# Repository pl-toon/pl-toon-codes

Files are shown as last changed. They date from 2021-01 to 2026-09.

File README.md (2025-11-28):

# PL-TOON
Repository for a multi agent experimental platooning platform 

# Platform in action (Youtube Link)
PL-TOON Description and Example. Spanish audio with English subtitles (activate them in settings):
https://youtu.be/QAIMSYgBqKo

# Platoon of trains - 2024 version
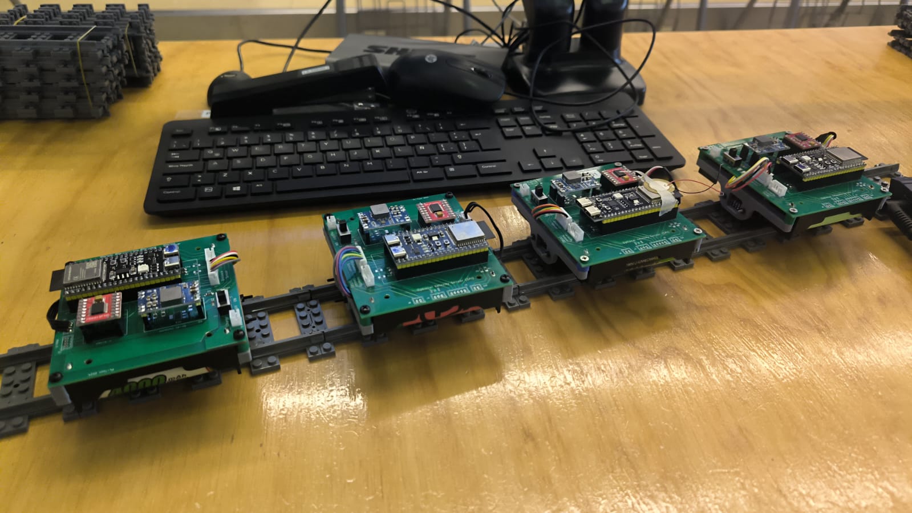
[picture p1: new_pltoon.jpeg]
Platoon


# Connection Diagram (Old)
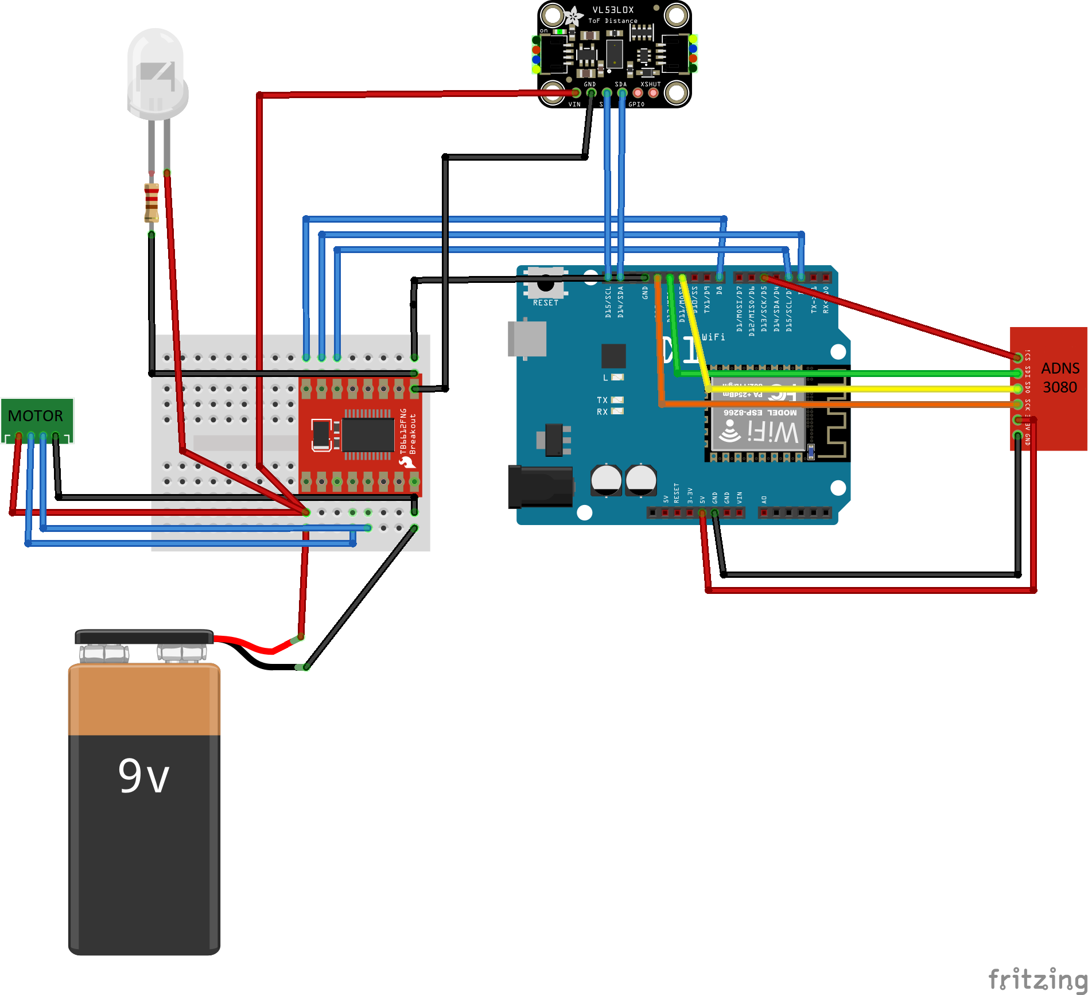
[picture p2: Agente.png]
Single Agent Connection Diagram


# Platform (Old)
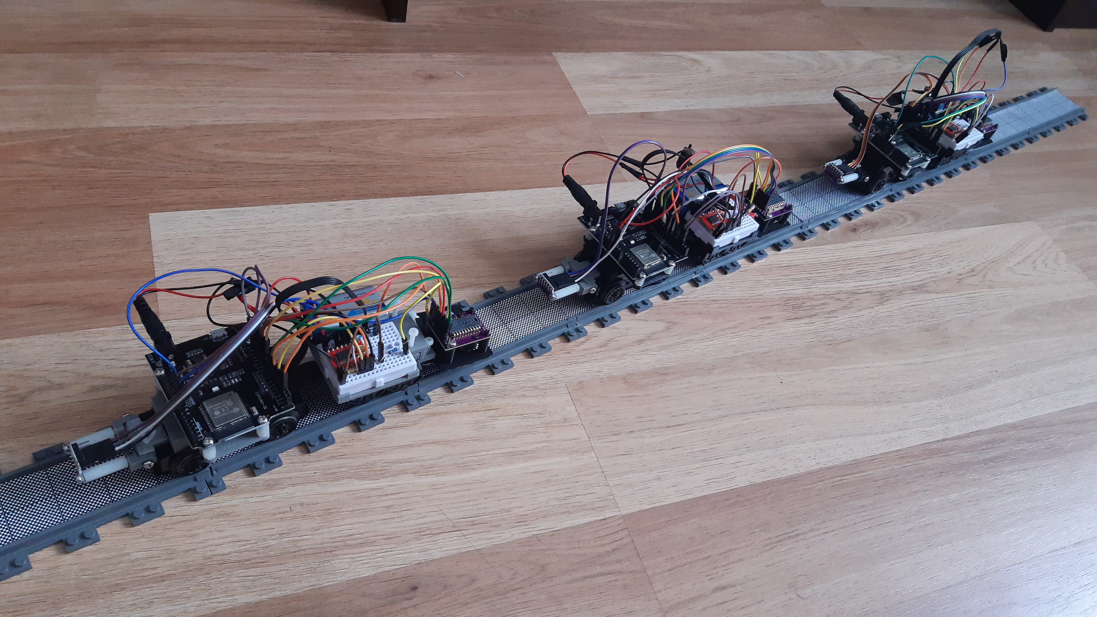
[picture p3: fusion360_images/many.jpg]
Many agents real


# Acknowledgements
The development of the PL-TOON platform has been supported by the Fondecyt grant 11221365.

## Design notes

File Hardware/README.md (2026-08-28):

# PLTOON Hardware

The hardware for PLTOON was designed using Kicad v8.0. 
All the Kicad files can be found in [this folder](/Hardware/Kicad/)

At the core of the PCB, there is an ESP32S3 devBoard [(Schematic)](https://dl.espressif.com/dl/schematics/SCH_ESP32-S3-DevKitC-1_V1.1_20221130.pdf). It is powered using a DCDC converter module (DC-DC Buck Converter Mini 560) that takes 7.4V  (two 18350 Batteries in series) and gives a regulated 5V output voltage. The purpose of having a DCDC converter is to improve efficiency. Nevertheless, there is an option to use an LDO instead, which needs to be populated on the board. This option has not been used nor tested. 
The ESP32S3 internally regulates the 5V to generate 3.3V, which is available for the rest of the electronics.  

The 18350 batteries can be charged through the J2 connector by switching SW1 to the Off/Chg state. There is no protection for reverse polarity, so it is up to the user to connect it correctly. When no charger is connected, the PLTOON remains OFF with this SW1 position. 
The power from the battery is supplied to the rest of the circuit by moving the switch SW1 to ON, which turns the LED1 ON (if the batteries are connected correctly) and LED2 ON (if the 5V of the DCDC converter is being supplied). Resistors R1 and R6 were chosen to be 330 Ohm, but they can be increased in value if we want to dim the LED light. 

A TB6612FNG H-Bridge is connected to the ESP32S3, and two motors can be driven by connecting them to J8 and J9 connectors. 

A distance sensor like VL53L0X can be connected to J1 using I2C. Other GPIOs are available in case they are needed. Pull-up resistors R2-R5 are not populated in the board, but are available for use. 

A Velocity sensor can be connected to USB-OTG by connecting it directly to the right-hand side USB-c connector of the ESP32S3 devBoard or to connector J7. J7 can also be used to flash the ESP32S3 devBoard using USB-OTG.
An SPI velocity sensor can be connected to connectors J5, J4 and J6 (depending on the signals that are needed). 

A top view of the rendered 3d PCB design in Kicad is shown below. 

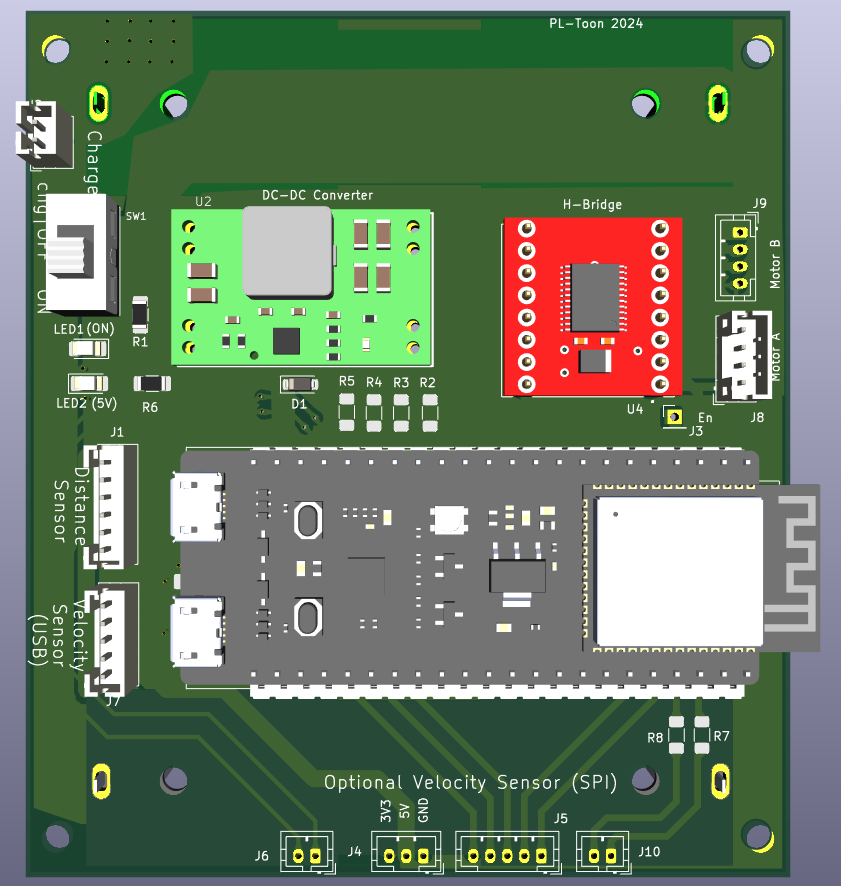
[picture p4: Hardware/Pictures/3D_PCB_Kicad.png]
3d Rendering


A bottom view of the rendered 3d PCB design in Kicad is shown below. 
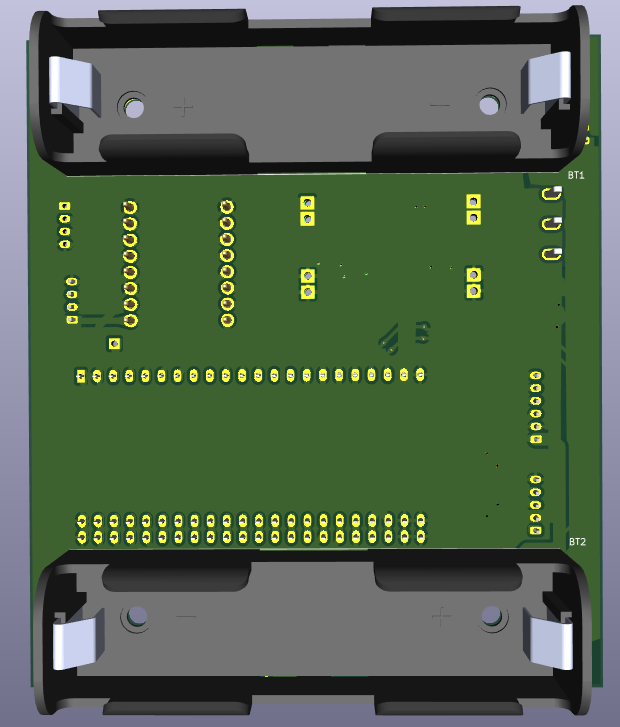
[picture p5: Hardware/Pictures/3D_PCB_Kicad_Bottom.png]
3d Rendering bottom


# Finished PCB
Some pictures of the assembled PCBs are shown below. 

Charging the batteries
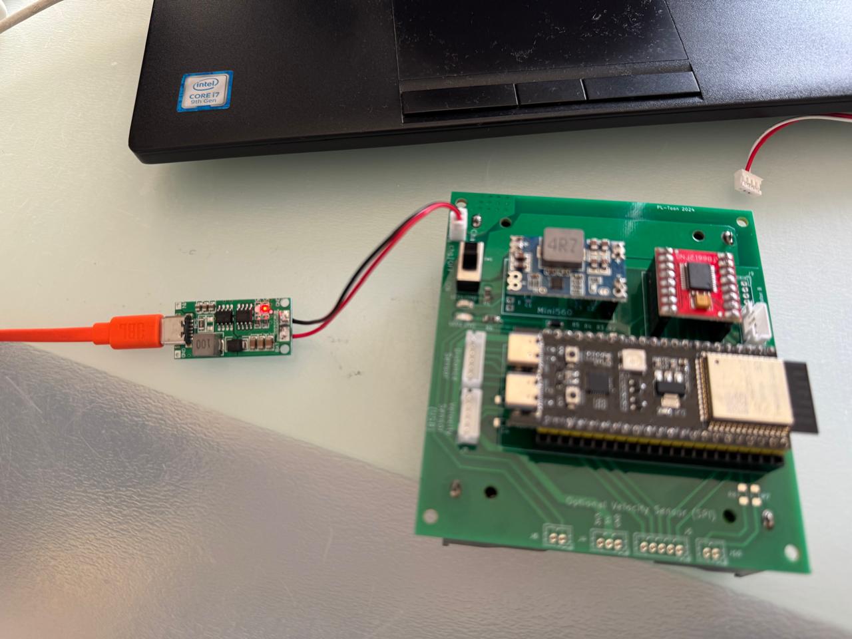
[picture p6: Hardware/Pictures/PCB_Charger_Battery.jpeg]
PCB Charger


Using the H-bridge with a DC motor connected
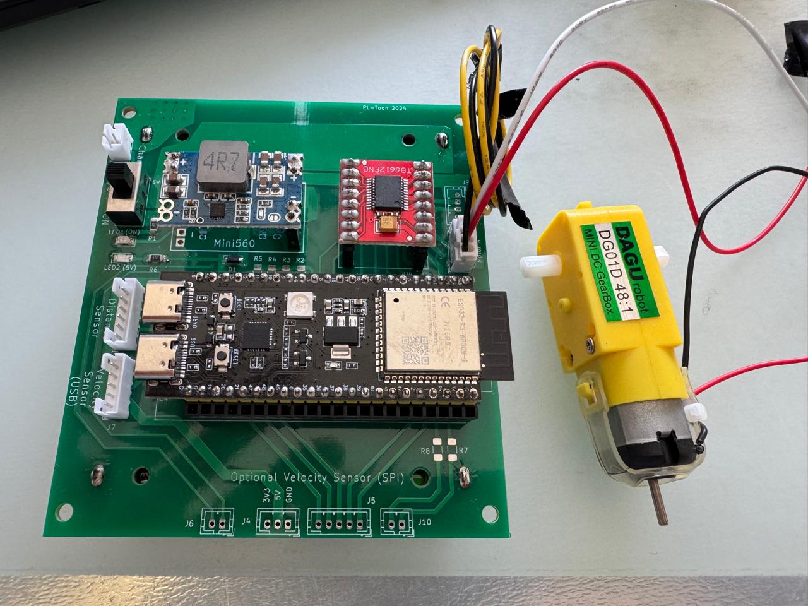
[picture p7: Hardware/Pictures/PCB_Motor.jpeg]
PCB motor


USB-OTG connected 
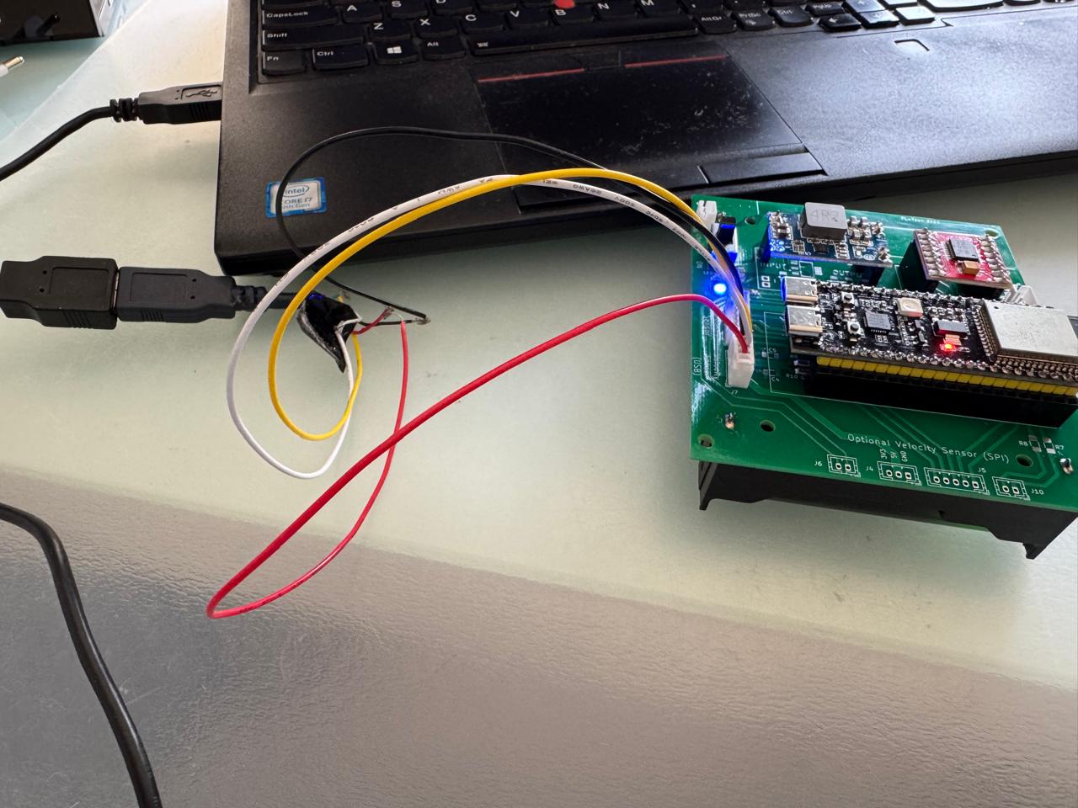
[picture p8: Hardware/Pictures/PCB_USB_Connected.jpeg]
PCB USB


# Schematic in pdf
[Schematic in pdf](/Hardware/Kicad/PL_Toon.pdf)

# BOM 
The bill of Material can be found [here](/Hardware/Kicad/BOM_PLTOON)

# Production Files (Gerber)
The .zip file used for producing the PCBs can be found [here](/Hardware/Production_Files)

# 3d Step file
[3d Step File](/Hardware/Kicad/PL_Toon_3D.step)

# 3d Printed Parts
The 3MF models for the printed train parts can be found [here](/Hardware/3D_Printed_Parts).

The chassis is made of two parts, a front one and a rear one. Each of them comes in two versions: the file ending in `_IMPRIMIR` holds a single copy of the part, and the one ending in `_DUPLICADAx8` is a plate with 8 copies already arranged for printing a full batch.

| File | Description |
| --- | --- |
| [PIEZA_FRONTAL_TREN_IMPRIMIR.3mf](/Hardware/3D_Printed_Parts/PIEZA_FRONTAL_TREN_IMPRIMIR.3mf) | Front chassis part, single copy |
| [PIEZA_FRONTAL_TREN_DUPLICADAx8.3mf](/Hardware/3D_Printed_Parts/PIEZA_FRONTAL_TREN_DUPLICADAx8.3mf) | Front chassis part, plate with 8 copies |
| [PIEZA_POSTERIOR_TREN_IMPRIMIR.3mf](/Hardware/3D_Printed_Parts/PIEZA_POSTERIOR_TREN_IMPRIMIR.3mf) | Rear chassis part, single copy |
| [PIEZA_POSTERIOR_TREN_DUPLICADAx8.3mf](/Hardware/3D_Printed_Parts/PIEZA_POSTERIOR_TREN_DUPLICADAx8.3mf) | Rear chassis part, plate with 8 copies |
| [Arandela_trencito.3mf](/Hardware/3D_Printed_Parts/Arandela_trencito.3mf) | Washer, single copy |

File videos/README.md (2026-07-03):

# Closed-loop experiment videos

Short recordings of the single-agent distance-regulation experiments referenced
in the mobile-dashboard paper. Clips are re-encoded (H.264, CRF 28, max width
1280 px) to keep file sizes small.

| File | Shows | Firmware | Setup |
|---|---|---|---|
| `single_train_demo_2026-07-03.mp4` | Single-train closed-loop distance regulation, current build | 2.4.1 | Untethered (matches the paper's reported runs) |
| `dashboard_live_2026-07-03.mp4` | The web dashboard plotting a live PID step (18→28 cm) in real time, with a mid-run setpoint change to 22 cm; driven entirely through the page UI over the train's WebSocket | 2.4.1 | Untethered; screen capture of the dashboard served by the train at 192.168.4.1 |
| `zn_gain_progression.mp4` | Ziegler–Nichols proportional-gain progression toward marginal stability | 2.3 | USB-tethered |
| `pid_step.mp4` | Full PID controller tracking a setpoint step | 2.3 | USB-tethered |

**Note on firmware.** The `zn_gain_progression` and `pid_step` clips were
recorded on firmware 2.3 with the agent USB-tethered. That earlier configuration
runs the control loop more slowly (~95 ms vs. the current 50 ms) and the cable
adds drag, so the ultimate gain observed in those clips is lower than the
$K_u \in [64, 80]$ range reported in the paper (which comes from firmware 2.4.1,
untethered). They are included to illustrate the qualitative phenomena — the loop
crossing from well-damped toward marginal stability, and PID step tracking — not
the exact numerical values in the text.

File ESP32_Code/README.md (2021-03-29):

## Index
- [Programming the Agents](#how-to-program-the-agents)
- [Running the Code](#running-the-code)
	* [Initial Setup](#initial-setup)
	* [Experiments](#performing-an-experiment)
---

## How to Program the Agents

The code is developed for the ESP32 board using the Arduino IDE libraries to compile the code. The most straightforward method to compile and run the codes, is to install the ESP32 libraries for Arduino and upload the code to the board within the same IDE. (You can watch how to do this [here](https://www.youtube.com/watch?v=mBaS3YnqDaU))

The [LeaderAgent](https://github.com/pl-toon/pl-toon-codes/tree/main/ESP32_Code/LeaderAgent) code has to be uploaded to the train that will go in front of the platoon, while the [PIDAgents](https://github.com/pl-toon/pl-toon-codes/tree/main/ESP32_Code/PIDAgents) code is meant to be used by the following agents that need to control their own speed and distance respect to the next agent in front.

In both cases you have to manually set in the code the `SSID` and `Password` of the Wi-Fi network to connect, as well as the `IP` and `Port` of the MQTT server.

***Note**: Before uploading the code, make sure to [calibrate the lens](https://github.com/pl-toon/pl-toon-codes/tree/main/ESP32_Code/Misc/Camera_Calibration) of the optical sensor in order to get a clear image on the checkerboard pattern and therefore obtain proper measurements of the velocity.*

---

## Running the Code
### Initial Setup

After powering on the agent. An initial setup and calibration process is made before is available to run experiments. This procedure applies to both the leader and following agents. The setup consists of the following (in the same order):
1) The MCU connects to the Wi-Fi network and the respective MQTT server located in the same local network.
2) The dead-band zone detection of the DC motor is performed. In this step, the motor speed is gradually increased until the train moves. It is important that the LED light at the back of the train is turned on since the measurement of the optical sensor is used to detect movement.
3) The camera calibration is performed. In this stage is important that the train has an object in front so it can measure its distance to the object. The train moves forward for about a second and compares the distances measurements to the object against the distance traveled detected by the camera. ***(WIP)***

At each stage, a message telling if the step was successful or not, is printed by the serial port. After all the steps are done the train is ready to run experiments!

### Performing an Experiment

All of the commands to run the experiment are sent by any device (e.g. laptop or smartphone) using the MQTT protocol. You can edit the parameters of the agents such as the motor speed of the leader, or the PID gains of the rest of the platoon.

The following list details how to change the respective parameters specifying the MQTT topic and type of message to send:

| Command | Topic | Type of Message  |
|---|---|---|
| Change the motor speed (Leader) | trenes/carrol/u | Integer  |
| Position Setpoint | trenes/ref | Float [cm] |
| Position PID Gains | trenes/carroD/p<br>trenes/carroD/i<br>trenes/carroD/d | Float |
| Velocity PID Gains | trenes/carroD/p_v<br>trenes/carroD/i_v<br>trenes/carroD/d_v | Float |
| Leader Following Constant $\alpha$ | trenes/alpha | Float (>=0) |
| Time Headway Constant $h$ | trenes/h | Float (>=0) |
| Controller Sample Time | trenes/carroD/ts | Integer [ms] |

After editing the parameters, the following sequence of commands have to be sent in order to start an experiment:
1. Send the message `"True"` to the topic `trenes/sync` to synchronize all the agents. After this, the PID agents will start controlling and they will move to achieve the position setpoint defined beforehand.
2. Send the message `"True"` to the topic `trenes/start` to send the signal to the leader agent to start the experiment. The Leader will start to advance with the defined motor speed and will stop until it encounters an obstacle in front.

To learn more about how to acquire the sensors data and other variables of interest from the agents, check the section [CaptureData](https://github.com/pl-toon/pl-toon-codes/tree/main/CaptureData/esp_write_csv) in this repository.

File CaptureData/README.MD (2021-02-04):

# From https://github.com/thomasfla/Linux-ESPNOW
# Before using this code
Do not forget to turn on monitor mode and choose the right channel on your wireless interface card.

Here is a exmaple on how to do it : 
```
sudo ifconfig wlp5s0 down
sudo iwconfig wlp5s0 mode monitor
sudo ifconfig wlp5s0 up
sudo iwconfig wlp5s0 channel 1 
```

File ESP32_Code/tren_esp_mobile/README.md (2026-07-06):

# Tren CE — Mobile Firmware (Standalone)

ESP32-based train controller with a built-in WiFi access point and mobile web dashboard. Connect a phone to the ESP32's WiFi, open the browser, and run PID / Step Response / Deadband Calibration experiments. No router, no laptop, no MQTT broker required.

This folder is **self-contained**: firmware (`.ino`), partition table, web dashboard (`data/`), and these instructions. If you received only this folder, you have everything you need.

---

## Contents

```
tren_esp_mobile/
├── README.md               ← This file
├── tren_esp_mobile.ino     ← Main firmware (~1230 lines)
├── partitions.csv          ← Custom partition table (1.5MB app + 1.5MB LittleFS)
└── data/
    ├── index.html          ← Mobile dashboard UI
    ├── uplot.min.js        ← Chart library (bundled, no CDN)
    └── uplot.min.css       ← Chart styles
```

No external assets — the dashboard works fully offline once flashed.

---

## Hardware

- ESP32-S3 Dev Module (4MB flash)
- VL53L0X Time-of-Flight distance sensor (I2C: SDA=GPIO 10, SCL=GPIO 9)
- Motor driver with these connections:
  - `STBY = GPIO 7`
  - `FWD  = GPIO 8`
  - `BACK = GPIO 18`
  - `PWM  = GPIO 17`
- USB cable for programming
- Phone or tablet (any modern browser)

---

## Software Prerequisites

- **Arduino IDE** 2.x (or 1.8.x)
- **ESP32 Board Package** v3.x — install `esp32` by Espressif in the Board Manager
- **esptool.py** + **mklittlefs** — bundled with the ESP32 core; paths shown below

### Required Arduino Libraries (Library Manager → Install)

| Library | Author | Version |
|---|---|---|
| ESPAsyncWebServer | ESP32Async (mathieucarbou) | v3.0+ |
| AsyncTCP | ESP32Async (mathieucarbou) | latest |
| ArduinoJson | Benoit Blanchon | v7.x |
| PID_v1_bc | — | latest |
| VL53L0X | Pololu | latest |

LittleFS is built into the ESP32 core — no separate install needed.

---

## Installation

### 1. Open the sketch

Open `tren_esp_mobile.ino` in Arduino IDE. The `.ino` file must remain in a folder named `tren_esp_mobile/` (Arduino IDE requirement).

### 2. Board settings

| Setting | Value |
|---|---|
| Board | ESP32S3 Dev Module |
| Partition Scheme | Custom (auto-detects `partitions.csv`) |
| Flash Size | 4MB |
| Upload Speed | 921600 |
| Port | Your ESP32's serial port |

### 3. Upload the LittleFS filesystem (web dashboard files)

This is the step most people miss. The firmware needs `index.html`, `uplot.min.js`, and `uplot.min.css` flashed to a separate filesystem partition.

**Recommended: command line** (the Arduino IDE plugin often fails on ESP32-S3):

```bash
# Build the LittleFS image from the data/ folder
~/Library/Arduino15/packages/esp32/tools/mklittlefs/4.0.2-db0513a/mklittlefs \
  -c data -s 0x170000 -p 256 -b 4096 /tmp/littlefs.bin

# Flash the image (replace port with your actual serial port)
esptool.py --chip esp32s3 --port /dev/cu.usbmodem1101 --baud 460800 \
  write_flash 0x190000 /tmp/littlefs.bin
```

- macOS path shown; on Windows use `%LOCALAPPDATA%\Arduino15\packages\esp32\tools\mklittlefs\...`, on Linux `~/.arduino15/...`
- `-s 0x170000` = LittleFS partition size from `partitions.csv`
- `0x190000` = LittleFS partition offset from `partitions.csv`
- Use the **UART** port, not the native USB-CDC port, on ESP32-S3
- **Close the Arduino Serial Monitor first**, or the port will be busy

**Alternative — Arduino IDE 2.x plugin** ([arduino-littlefs-upload](https://github.com/earlephilhower/arduino-littlefs-upload)):
1. Install the plugin (see plugin README)
2. `Tools → Upload LittleFS to ...`

**Alternative — PlatformIO**: `pio run --target uploadfs`

> Upload LittleFS **before** the firmware, or the first boot will log "LittleFS mount failed."

### 4. Upload the firmware

Press the Upload button in Arduino IDE (or `Ctrl+U`).

### 5. First-time configuration

Open the Serial Monitor at **115200 baud, line ending: Newline**. You should see:

```
*** TRAIN NOT CONFIGURED ***
Waiting for configuration...
```

Type:

```
SET_TRAIN:trainA:5555
```

The ESP32 will save the config to EEPROM, flash the LED 3 times, and reboot. After reboot:

```
TRAIN CONFIGURATION LOADED
Train ID: trainA
Starting WiFi Access Point...
  SSID: TrenCE-trainA
  Password: train123
  IP: 192.168.4.1
Setup Complete! Ready for mobile control.
```

The port number is stored but unused in mobile mode (it exists for compatibility with the laptop firmware).

### Serial commands

| Command | Description |
|---|---|
| `SET_TRAIN:id:port` | Configure train ID (e.g. `SET_TRAIN:trainB:5556`) |
| `GET_TRAIN` | Show current configuration |
| `RESET_TRAIN` | Clear config and reboot |
| `STATUS` | Same as GET_TRAIN |

### LED status

| Pattern | Meaning |
|---|---|
| Fast blink (5 Hz) | Not configured — waiting for `SET_TRAIN` |
| Slow blink (1 Hz) | AP active, waiting for phone |
| Solid ON | Phone connected via WebSocket |

---

## Using the Dashboard

1. On your phone, open WiFi settings and connect to **`TrenCE-trainA`** (or whatever train ID you configured)
2. Password: **`train123`**
3. Open a browser and go to **`http://192.168.4.1`**
4. If the phone warns "No Internet" — that's expected. Tap "Stay connected" or "Use this network anyway."

The dashboard has three experiment modes selected by tabs at the top.

### PID Control
Closed-loop distance tracking. Sliders: Kp (0–100), Ki (0–50), Kd (0–50), Reference (1–100 cm), Deadband (0–200 PWM). Parameters can be adjusted live while running. Chart shows distance, reference, and error.

### Step Response
Open-loop motor step. Sliders: Amplitude (0–Vbatt V), Duration (0.5–20 s), Battery Voltage (3.0–12.0 V), Direction. Three-phase execution: 5-sample warm-up → 3-sample baseline → step applied. Auto-stops when duration expires.

### Deadband Calibration
Ramps PWM from 0 until motion is detected. Sliders: Motion Threshold (0.01–1.0 cm), Direction. Result appears as a large number when done — tap **Apply Result to PID** to use as PID deadband.

### Data Export
- **Save CSV** — downloads chart data as `<mode>_<timestamp>.csv`
- **Save Plot** — downloads chart as PNG

Data is only available while the page is open. Export before closing or refreshing.

### Language / Theme / Presets
- **ES/EN** toggle (top-right) — full Spanish/English translation, saved in phone localStorage
- **Sun/moon icon** — dark/light theme, saved per phone
- **Presets** — save current parameters under a name, reload later. Stored on the phone, not the ESP32.

### Safety features
- **Auto-stop on phone disconnect** — if WiFi drops or browser closes, the ESP32 stops the motor
- **Deadband safety limit** — calibration aborts if PWM exceeds 800 without motion
- **PWM clamping** — motor PWM is constrained to 0–1024

---

## WebSocket Protocol (for developers)

Endpoint: `ws://192.168.4.1/ws`. All messages are JSON.

**Phone → ESP32 (commands):**
```json
{"t":"cmd","c":"kp","v":2.5}
{"t":"cmd","c":"start","m":"pid"}
{"t":"cmd","c":"stop"}
```

**ESP32 → Phone (data, ~11 Hz during experiment):**
```json
{"t":"d","m":"pid","ts":12345,"d":15.23,"r":10.0,"e":-5.23,
 "kp":2.5,"ki":0.8,"kd":1.2,"u":127.5,"pwm":177,"dir":1}
```

Full command/data field reference is in the firmware header comment (`tren_esp_mobile.ino`, lines 25–34).

---

## Troubleshooting

| Symptom | Fix |
|---|-----|
| Serial: `FATAL: Cannot start without LittleFS!` | LittleFS data not uploaded — repeat Step 3 |
| Phone shows "No Internet Connection" | Expected. Tap "Stay connected." On iOS, dismiss popup and open Safari manually |
| Browser can't reach 192.168.4.1 | Confirm phone is on `TrenCE-xxx` WiFi (not your home WiFi). Use `http://` not `https://` |
| Connection indicator stays red | WebSocket never opened. Hard-refresh the page. Check Serial Monitor for `[WS] Client #1 connected` |
| Sliders seem unresponsive | Sliders send on finger **release**, not while dragging. Check "Confirmed ESP32 Values" — they only update after ESP32 ack |
| Motor doesn't move (PID) | If Kp=Ki=Kd=0, PID output is 0. Start with Kp≈5–10 |
| Motor doesn't move (Step) | Both Amplitude and Duration must be > 0 |
| esptool: "Port is busy" | Close Arduino Serial Monitor before flashing |
| esptool: "Failed to write to target RAM" | Use the UART port, not the native USB-CDC port |
| Chart not updating | Chart updates only during a running experiment. First 5 points are discarded (sensor warm-up) |

---

## Sensor Notes

The VL53L0X is configured for a balance of speed and accuracy:

- Timing budget: 33 ms (default)
- Continuous read mode with data-ready polling
- 5-sample moving average + EMA blend (80% new / 20% previous)
- Invalid readings (>= 8190 mm) rejected, previous value kept
- Effective loop rate: ~12 Hz (33ms read + compute + send + 50ms delay)

Reducing the timing budget to 20 ms increases noise by ~28% — not worth it for closed-loop control.

---

## License & Credits

Built for UAI's MIN215 control systems course. Firmware version: `2.2-mobile`.

## v2.4.2 — step-mode brake phase

The step-response experiment gains an optional stop phase, configured over the
WebSocket before `start` (backward compatible; default is the legacy stop):

| Command | Values | Meaning |
|---|---|---|
| `brk_mode` | 0 / 1 / 2 | 0 = legacy stop (TB6612 short brake), 1 = coast (outputs high-Z), 2 = opposite-direction torque |
| `brk_pwm`  | 0–1023 | torque for `brk_mode` 2 (`brk_pwm` 0 = short brake with telemetry) |
| `brk_ms` | seconds  | brake-phase duration (max 5 s) |

Telemetry keeps streaming through the brake phase (`dir` reports the live motor
direction), which makes matched-speed stopping-distance comparisons per direction
possible — the diagnostic that separates drivetrain, driver, and sensing effects.

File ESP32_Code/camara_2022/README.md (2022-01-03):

# Pruebas Cámara 

## Enero 2, 2022

Prubeas dejando el 'scale' hard-coded.

Conclusiones:

- Funciona
- Sensor de distancia da una medición distinta comparado con una regla

- Scale (1) = 0.0079
- Scale (2) = 0.0124

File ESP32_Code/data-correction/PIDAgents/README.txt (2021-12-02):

Código basado en el archivo PIDAgents de la carpeta ESP32_Code.

Función data_correction recibe el valor recibido por el sensor y la medición anterior del carro (promedio de 4 mediciones), entrega la medición corregida.

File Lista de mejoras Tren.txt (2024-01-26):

Lista de mejoras Tren:
1. Conectar a esp32 el STBY (para poder controlar internamente).
2. Baterias en paralelo.
3. Conector micro USB soldado apegado a la orilla (para que no se suelte)
4. Tener salidas (pines) para otro motor y/o libres.
5. Un interruptor que corte de manera general.
6. Conectores JST para el motor y el sensor de distancia.

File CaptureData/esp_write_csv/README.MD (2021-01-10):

## Before using this code
Do not forget to turn on monitor mode and choose the right channel on your wireless interface card.

Here is a exmaple on how to do it : 
```
sudo ifconfig wlp0s20f3 down
sudo iwconfig wlp0s20f3 mode monitor
sudo ifconfig wlp0s20f3 up
sudo iwconfig wlp0s20f3 channel 1 
```

## How to run the code
To compile the code just use :
```
make
```

And to run the program :
```
sudo ./bin/exec <wifi_interface> <output_file.csv>
```
If no name for the output file is specified, a file named `data.csv` will be generated in the base directory. The structure of the output file is the following:
```
esp_id , pc_timestamp , esp_timestamp , position , velocity
```

## Plot the Data
You can plot the resulting data using `matplot_data.py`. Example:
```
python3 matplot_data.py <csv_file>
```
You can also plot the receiving data in "real time" using `matplot_realtime.py`.
```
python3 matplot_realtime.py <csv_file>
```
In both cases you require the `matplotlib` and `pandas` libraries for Python.

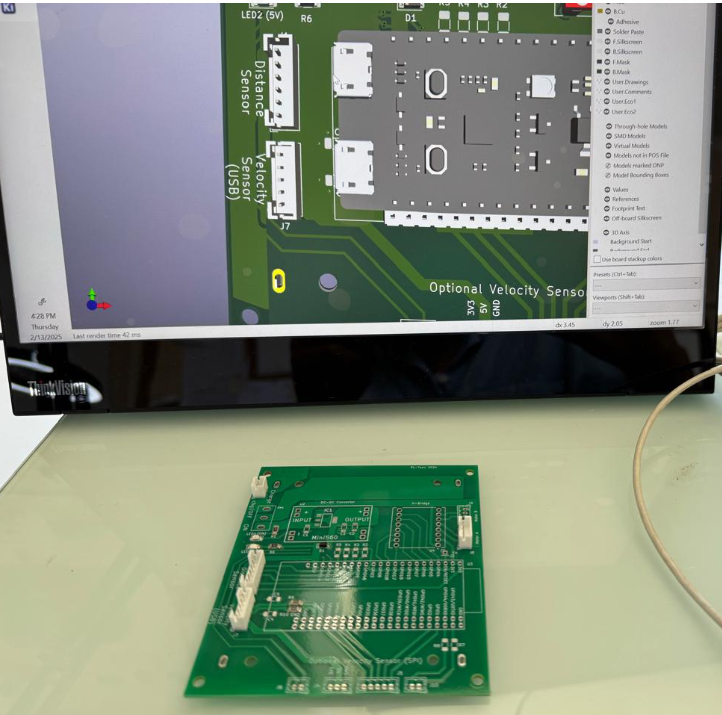
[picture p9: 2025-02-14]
Hardware/Pictures/PCB_Mounting_3d.png

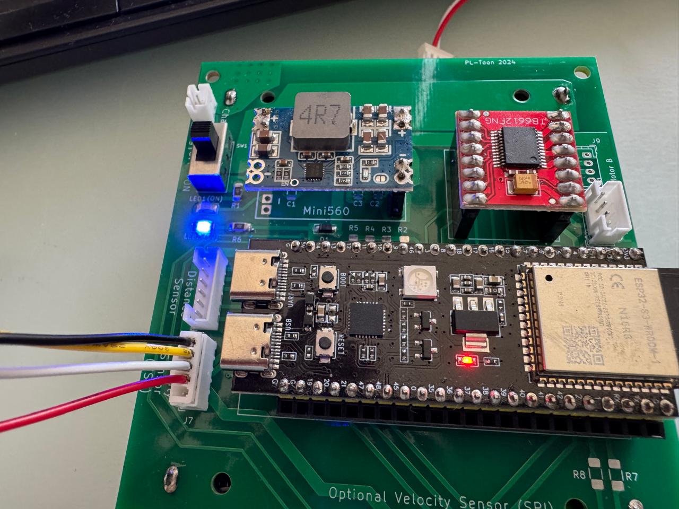
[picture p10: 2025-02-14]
Hardware/Pictures/PCB_USB.jpeg

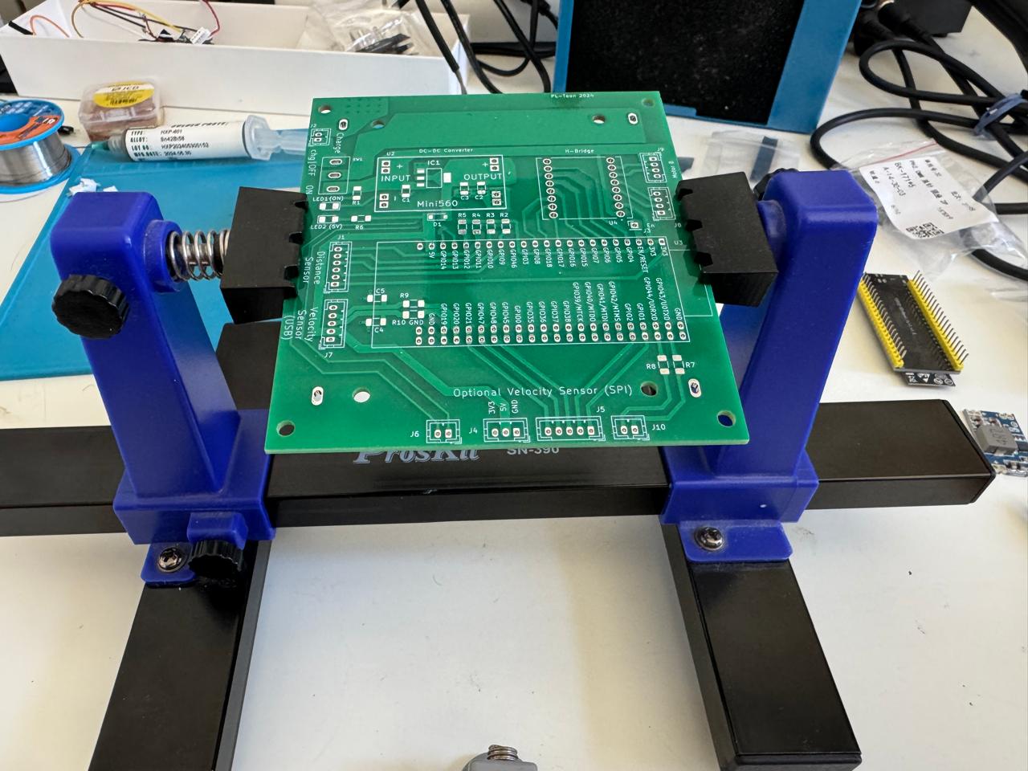
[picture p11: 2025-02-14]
Hardware/Pictures/PCB_Naked.jpeg

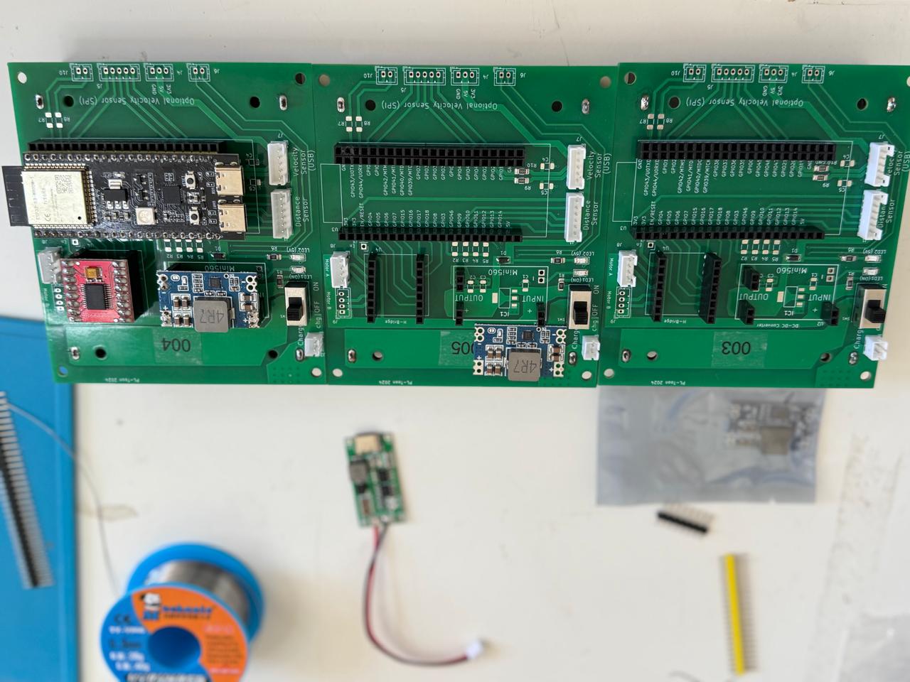
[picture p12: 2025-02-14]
Hardware/Pictures/ThreeBoards.jpeg

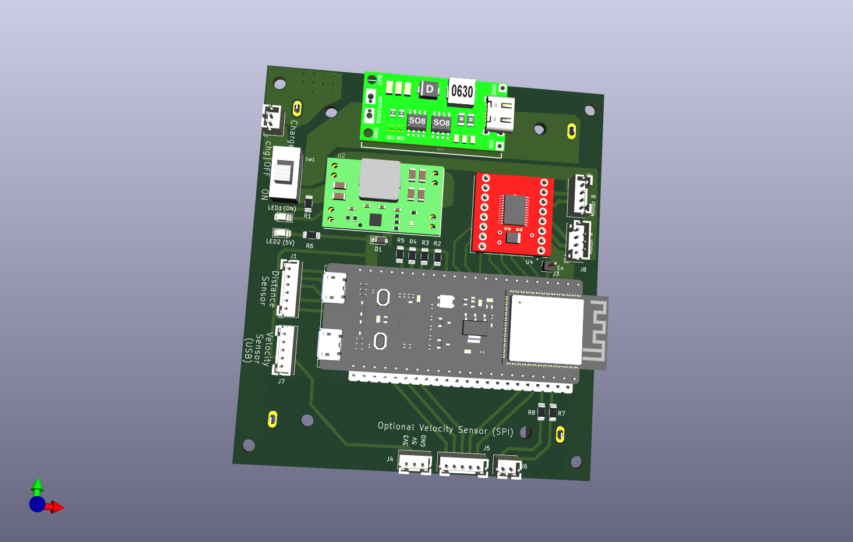
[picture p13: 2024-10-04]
Hardware/Kicad/PL_Toon.png

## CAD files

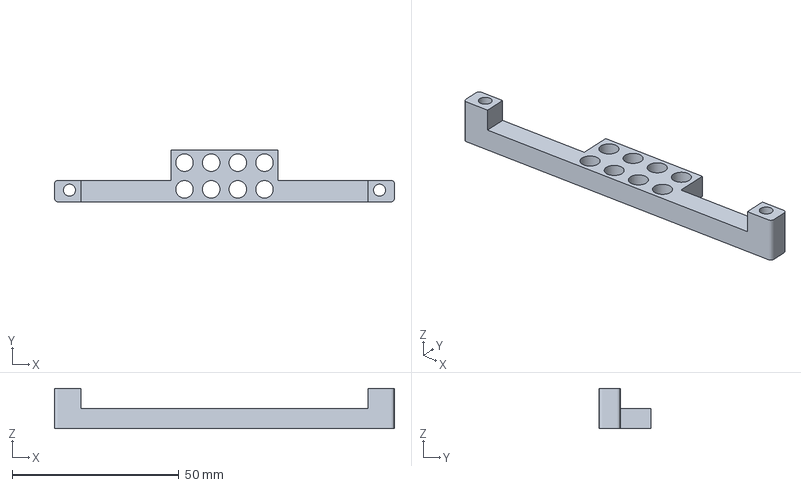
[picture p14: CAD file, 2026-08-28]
Hardware/3D_Printed_Parts/PIEZA_POSTERIOR_TREN_IMPRIMIR.3mf
102.0 x 15.5 x 12.0 mm

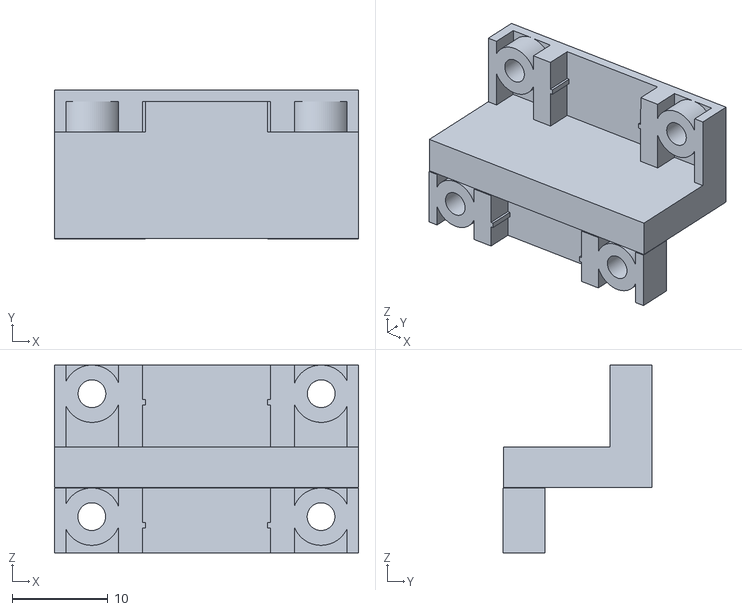
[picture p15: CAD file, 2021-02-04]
stl/Soporte_camara_bajo.stl
31.8 x 15.6 x 19.7

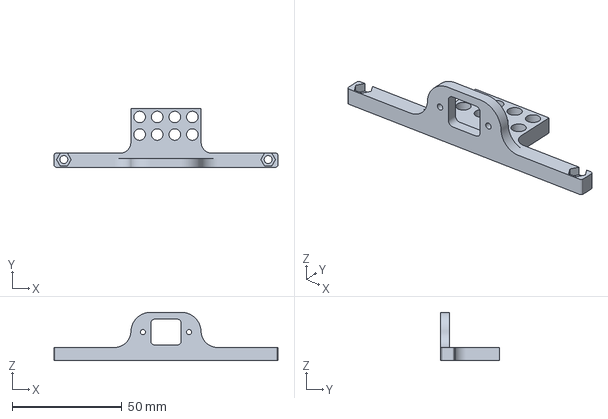
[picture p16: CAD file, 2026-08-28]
Hardware/3D_Printed_Parts/PIEZA_FRONTAL_TREN_IMPRIMIR.3mf
102.0 x 26.6 x 22.0 mm

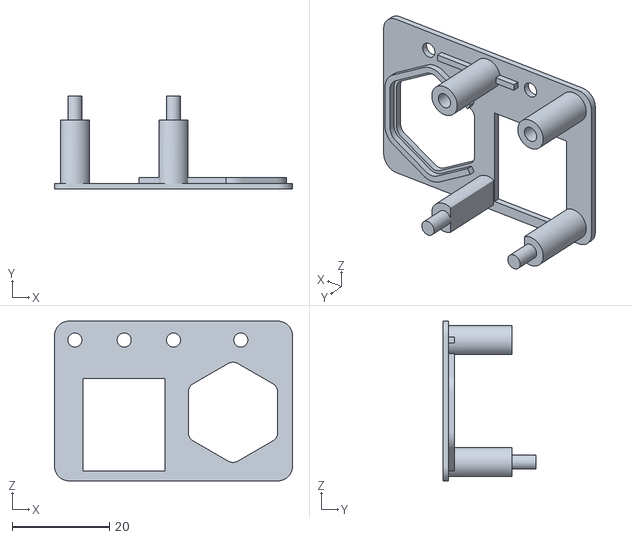
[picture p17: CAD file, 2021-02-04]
stl/soporte_camara.stl
49.0 x 19.2 x 32.9

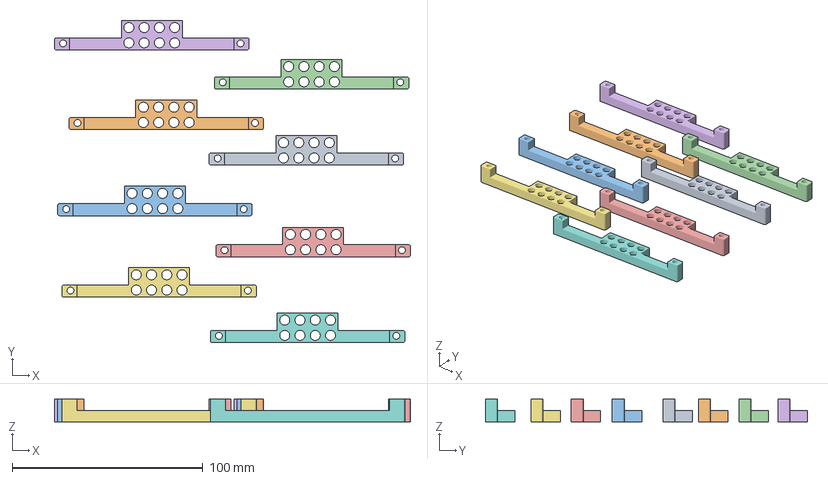
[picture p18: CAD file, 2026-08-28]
Hardware/3D_Printed_Parts/PIEZA_POSTERIOR_TREN_DUPLICADAx8.3mf
186.6 x 168.9 x 12.0 mm
tren_posterior.stl
tren_posterior.stl(1)
tren_posterior.stl(2)
tren_posterior.stl(3)
tren_posterior.stl(4)
tren_posterior.stl(5)
tren_posterior.stl(6)
tren_posterior.stl(8)

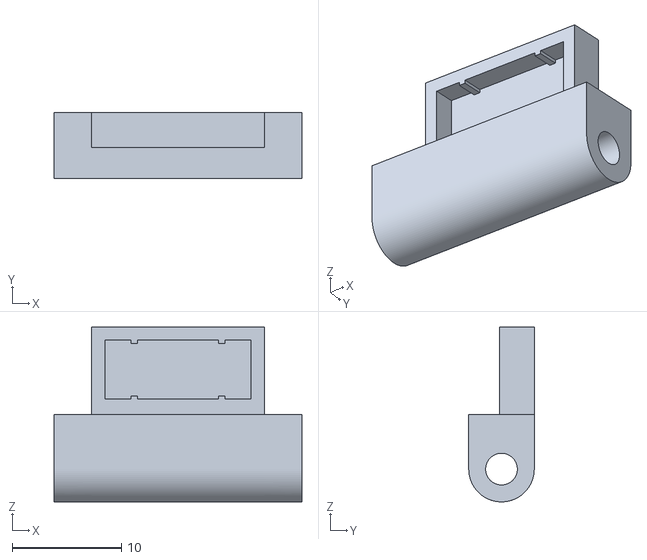
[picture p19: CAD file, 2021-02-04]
stl/sensor_frontal_base.stl
22.7 x 6.00 x 16.0

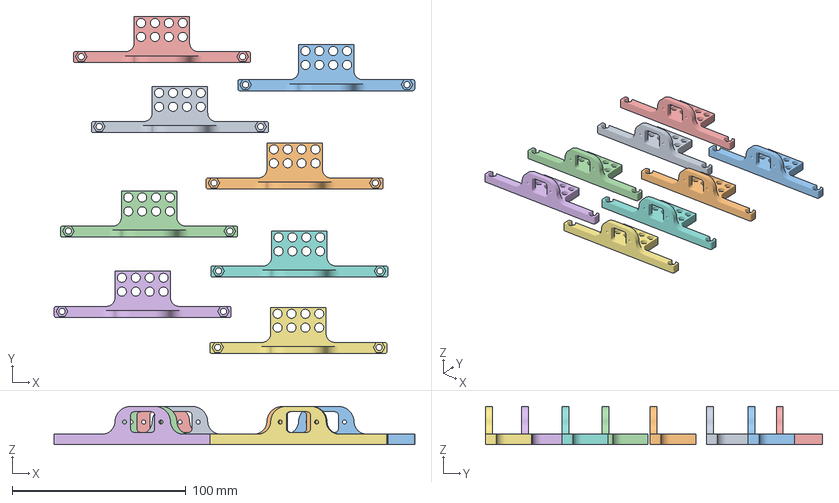
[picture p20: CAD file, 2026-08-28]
Hardware/3D_Printed_Parts/PIEZA_FRONTAL_TREN_DUPLICADAx8.3mf
207.8 x 194.2 x 22.0 mm
PIEZA_FRONTAL.stl
PIEZA_FRONTAL.stl(1)
PIEZA_FRONTAL.stl(2)
PIEZA_FRONTAL.stl(3)
PIEZA_FRONTAL.stl(4)
PIEZA_FRONTAL.stl(5)
PIEZA_FRONTAL.stl(6)
PIEZA_FRONTAL.stl(7)

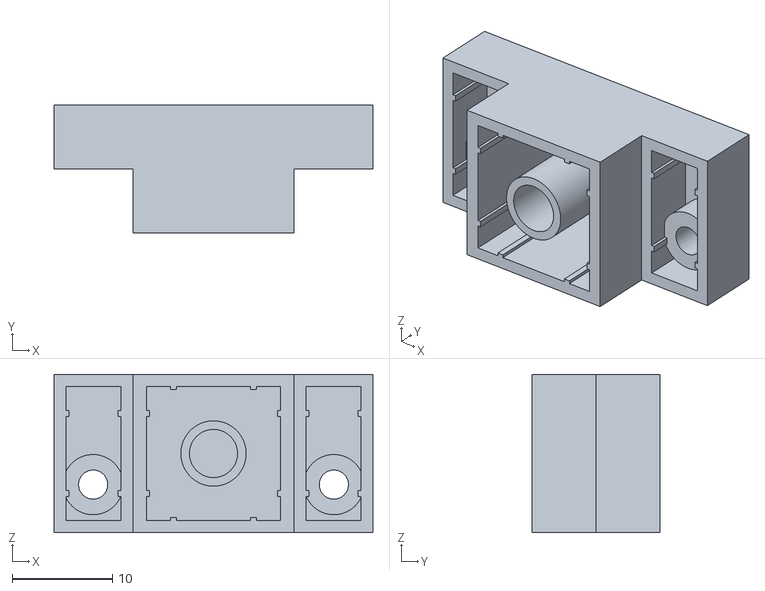
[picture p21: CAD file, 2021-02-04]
stl/lego_soporte_camara.stl
31.8 x 12.8 x 15.8

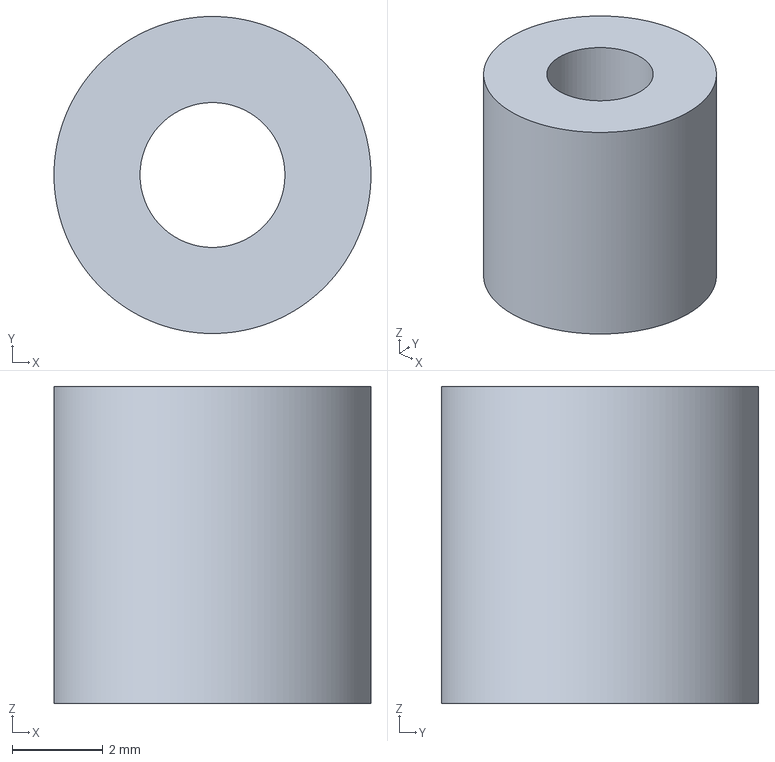
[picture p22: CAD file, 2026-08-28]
Hardware/3D_Printed_Parts/Arandela_trencito.3mf
7.00 x 7.00 x 7.00 mm

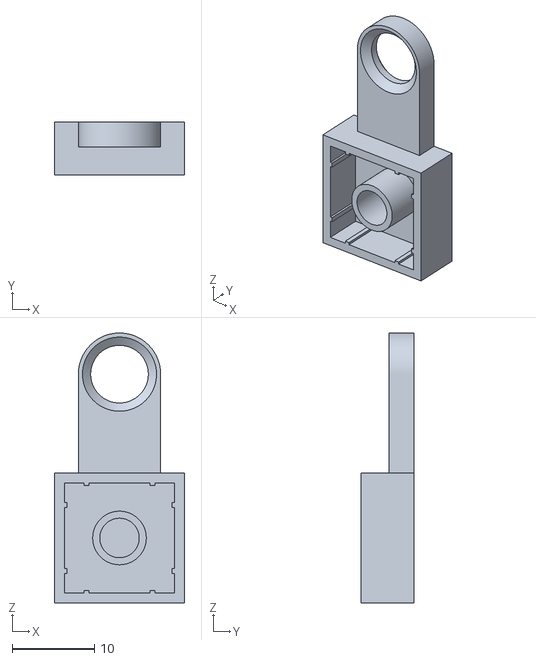
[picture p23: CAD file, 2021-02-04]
stl/pivote_eje_2.stl
15.8 x 6.40 x 32.8

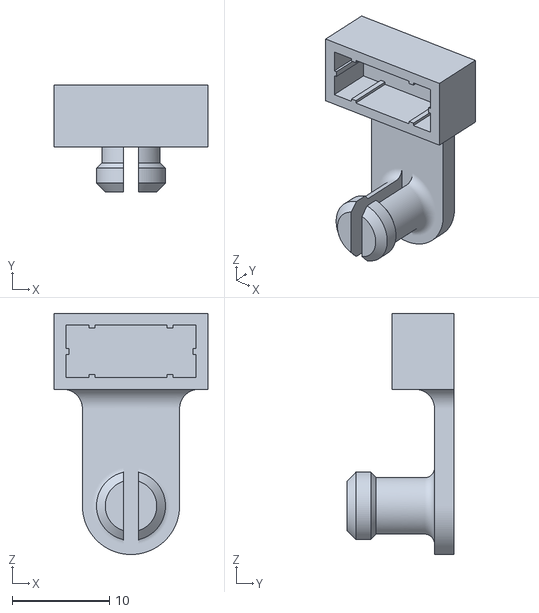
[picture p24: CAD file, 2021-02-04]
stl/pivote_eje_1.stl
15.8 x 11.0 x 24.8

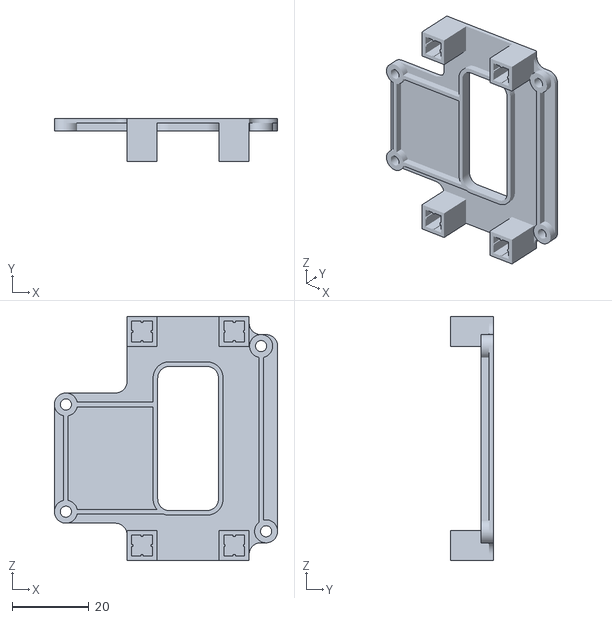
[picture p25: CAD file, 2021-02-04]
stl/lego_base_placa.stl
58.1 x 11.2 x 63.5

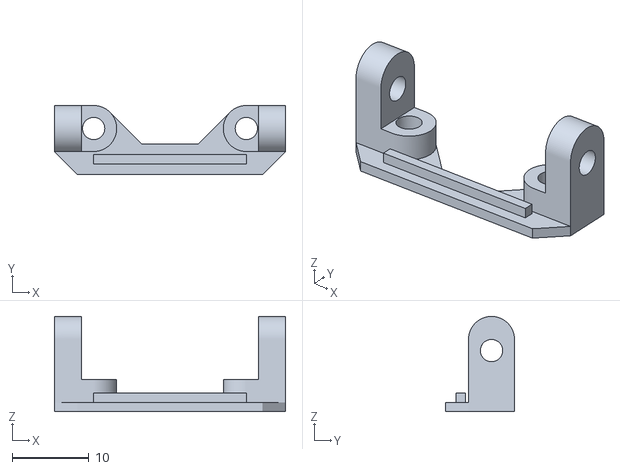
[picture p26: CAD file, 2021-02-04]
stl/sensor_frontal_soporte.stl
30.1 x 9.00 x 12.4

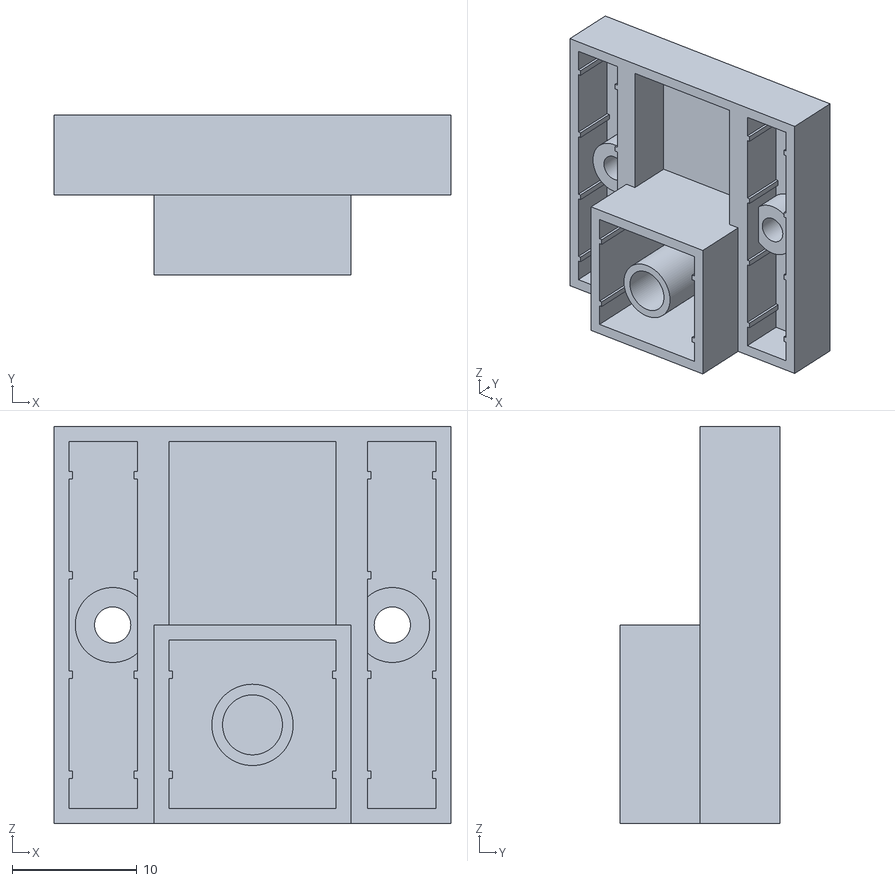
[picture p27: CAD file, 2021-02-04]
stl/lego_soporte_proto_bateria.stl
31.8 x 12.8 x 31.8

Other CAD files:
stl/soporte_proto_bateria.stl

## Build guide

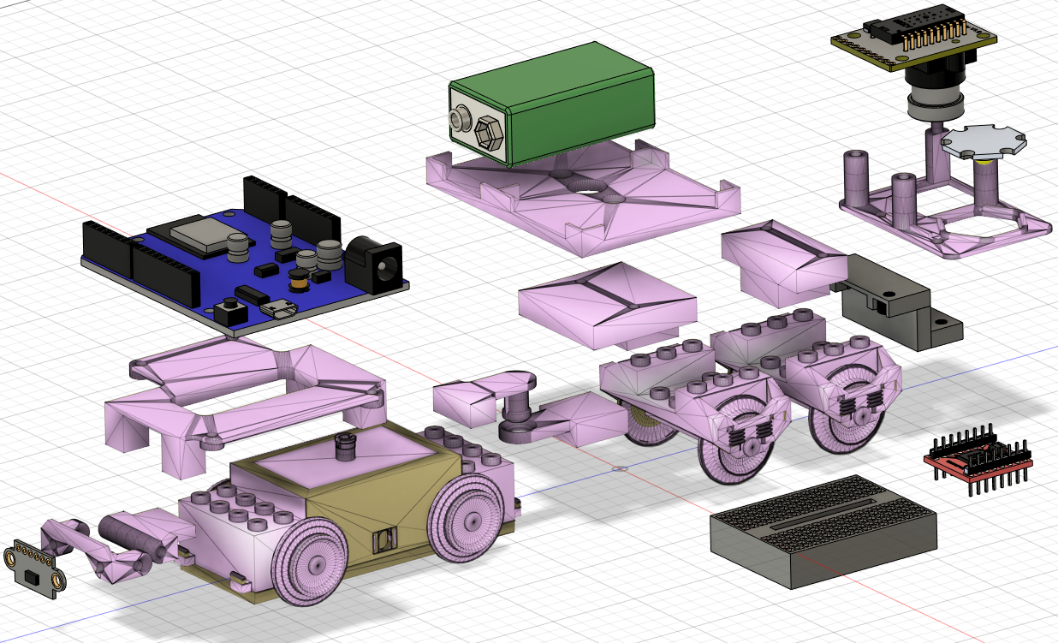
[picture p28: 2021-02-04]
fusion360_images/assembled.png

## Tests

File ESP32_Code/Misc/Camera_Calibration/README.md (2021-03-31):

## ADNS3080 Calibration

It is very important to manually adjust the lens of the sensor to get a clear image of the checkerboard pattern of the floor and therefore get an accurate measurement.

To do this you must upload the code `image_capture_ADNS3080.ino` to the train, and then use the script `ADNS3080ImageGrabber_(PYTHON2).py`* to be able to watch the image obtained by sensor. For this, run the script and open the serial port connected to the agent. Then, in the send button of the window, send an `I` through the serial port to obtain a continuous image from the sensor.

Here is an example of how the image should look like, and also an example of a blurry image of the floor pattern:

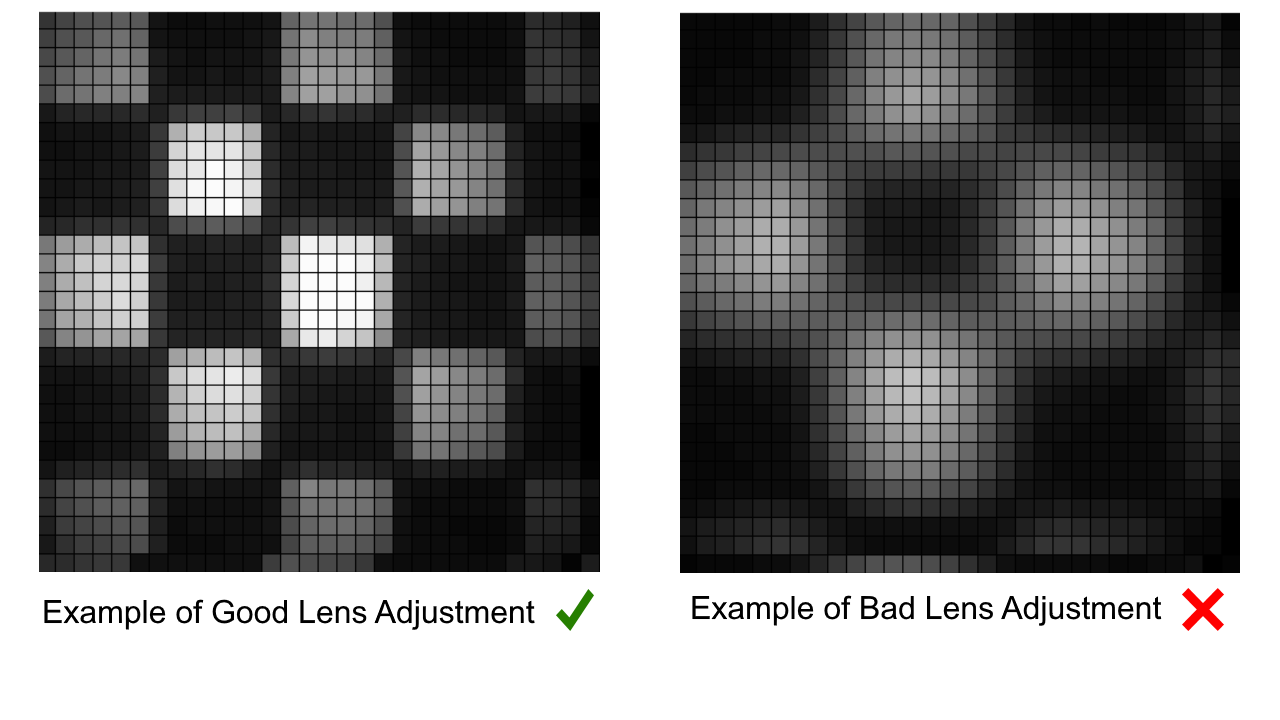
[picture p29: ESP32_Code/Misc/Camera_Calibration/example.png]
Example of Calibration


\* *As of now this script only runs on Python 2*

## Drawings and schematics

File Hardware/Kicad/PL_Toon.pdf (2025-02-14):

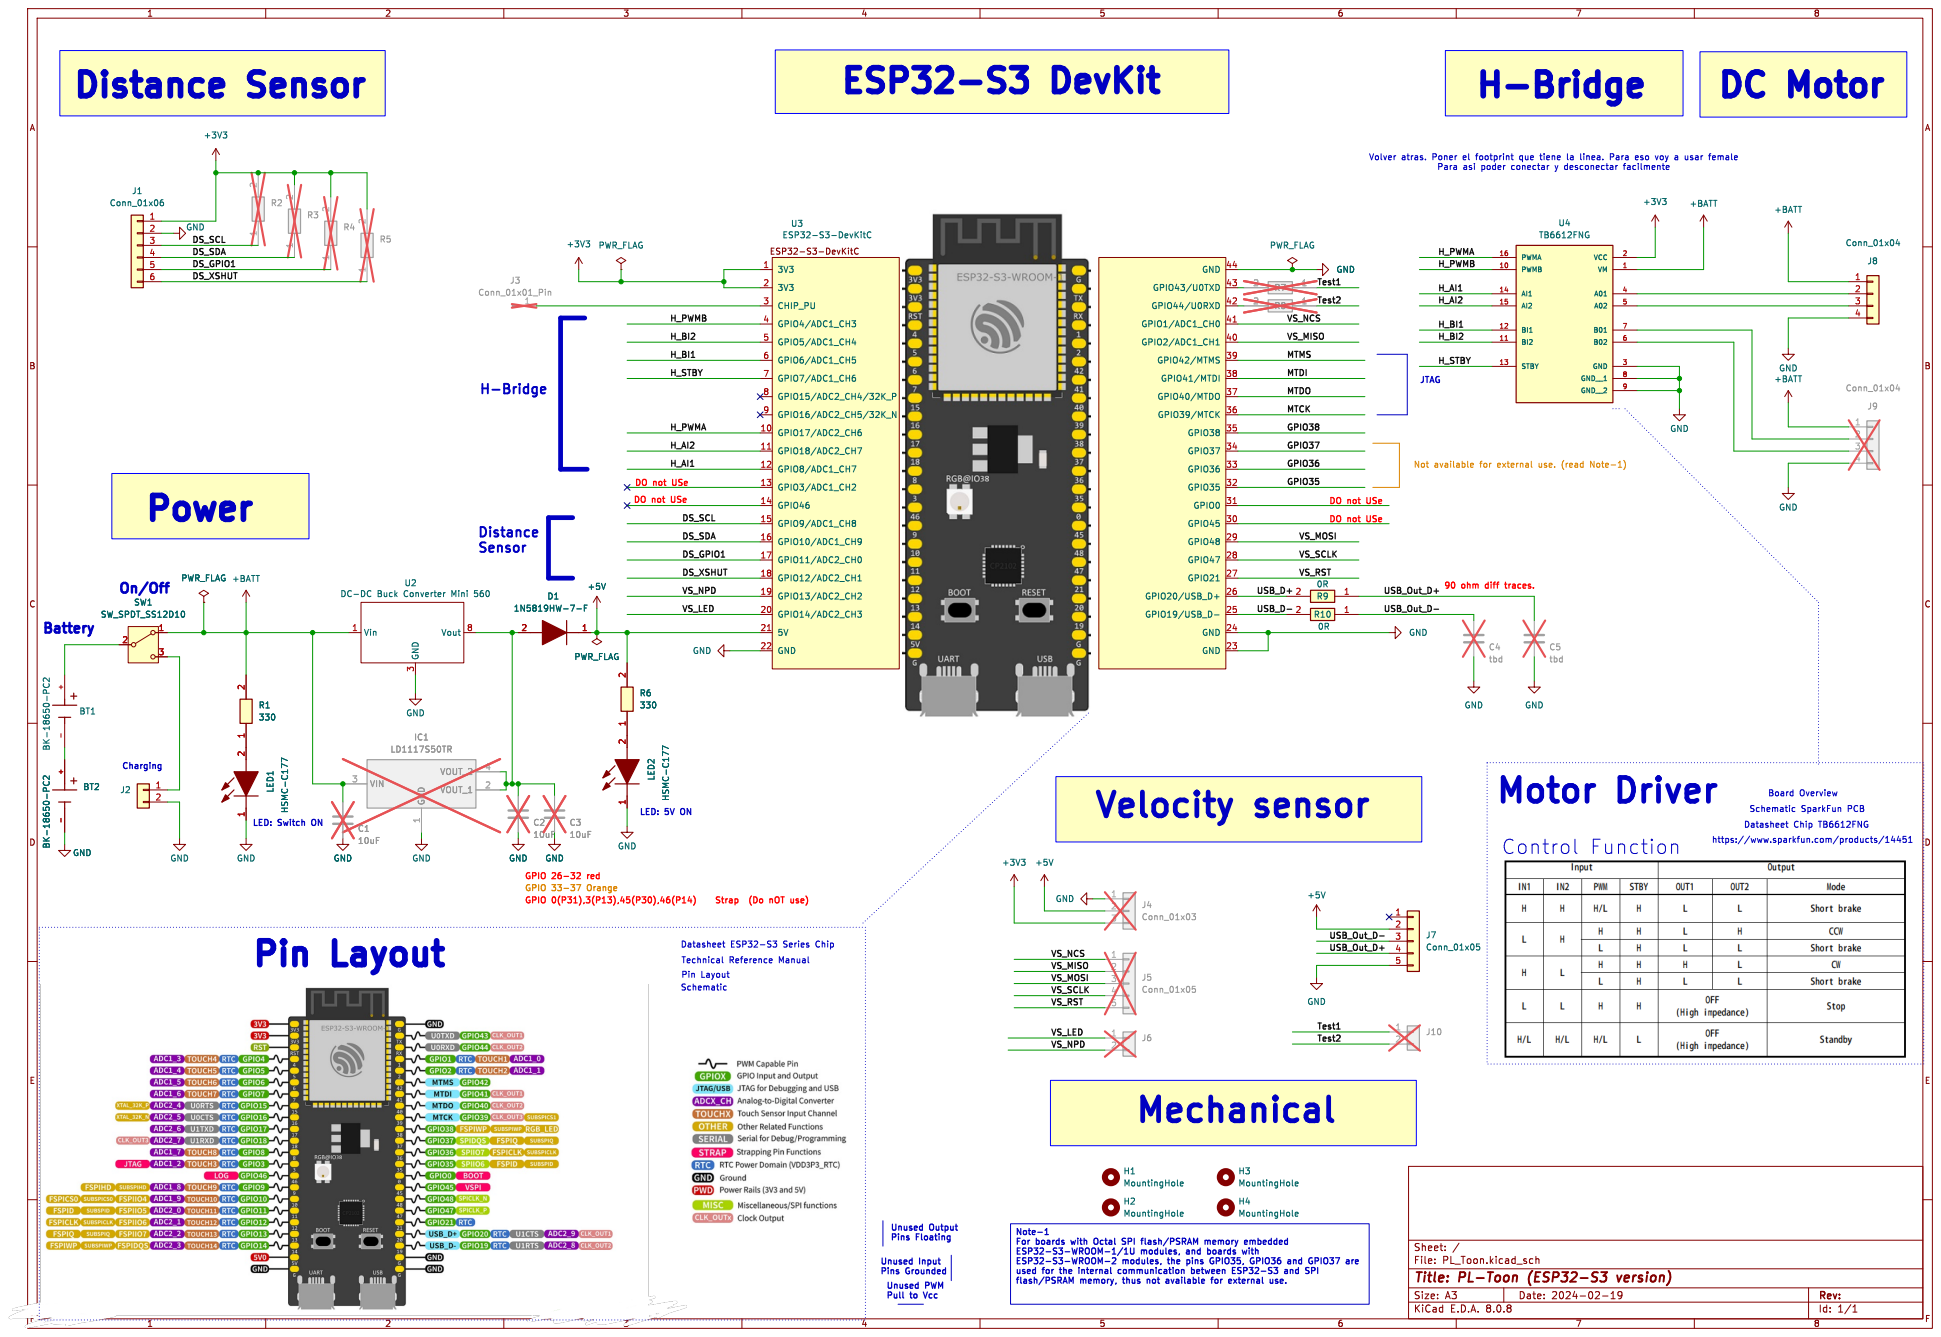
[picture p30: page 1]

Unused Input Pins Grounded Distance Sensor

1 2 R4 GND GND GND GND

H_STBY H_BI2 MTCK MTDI MTMS MTDO

DO not USe Battery

DO not USe LED: Switch ON

DO not USe Charging

3 Vout 8 U2 DC-DC Buck Converter Mini 560 +5V

https://www.sparkfun.com/products/14451 Unused Output Pins Floating

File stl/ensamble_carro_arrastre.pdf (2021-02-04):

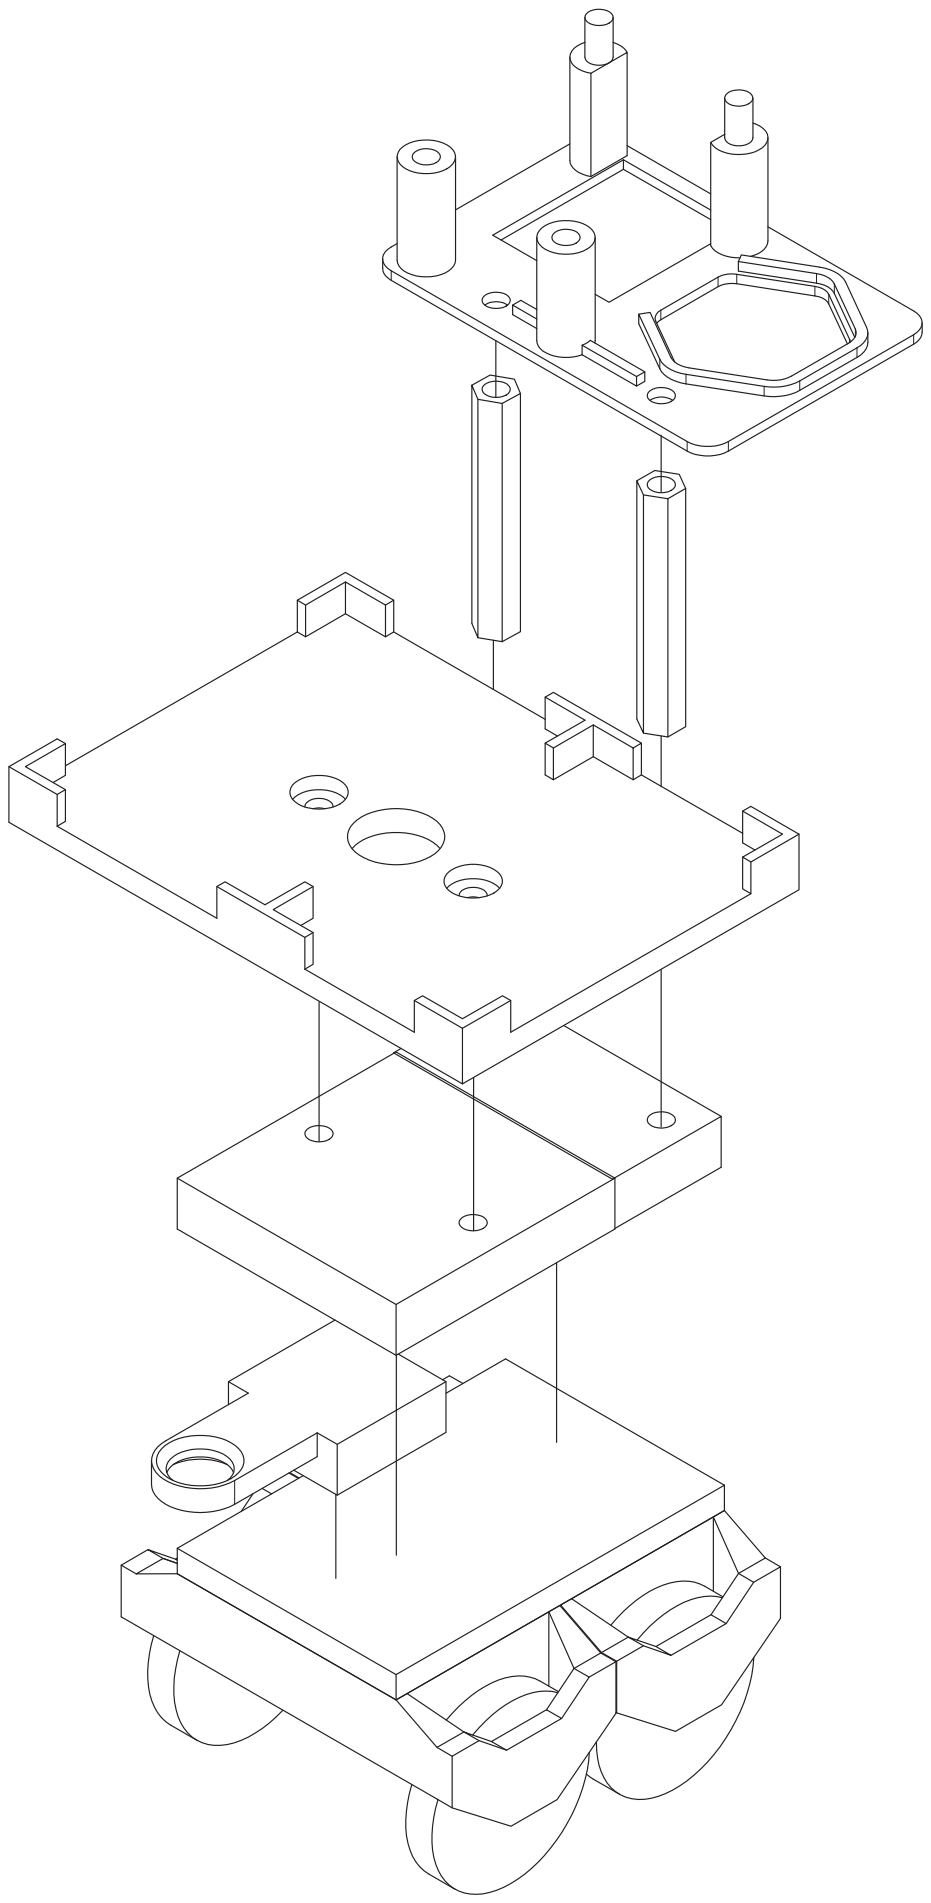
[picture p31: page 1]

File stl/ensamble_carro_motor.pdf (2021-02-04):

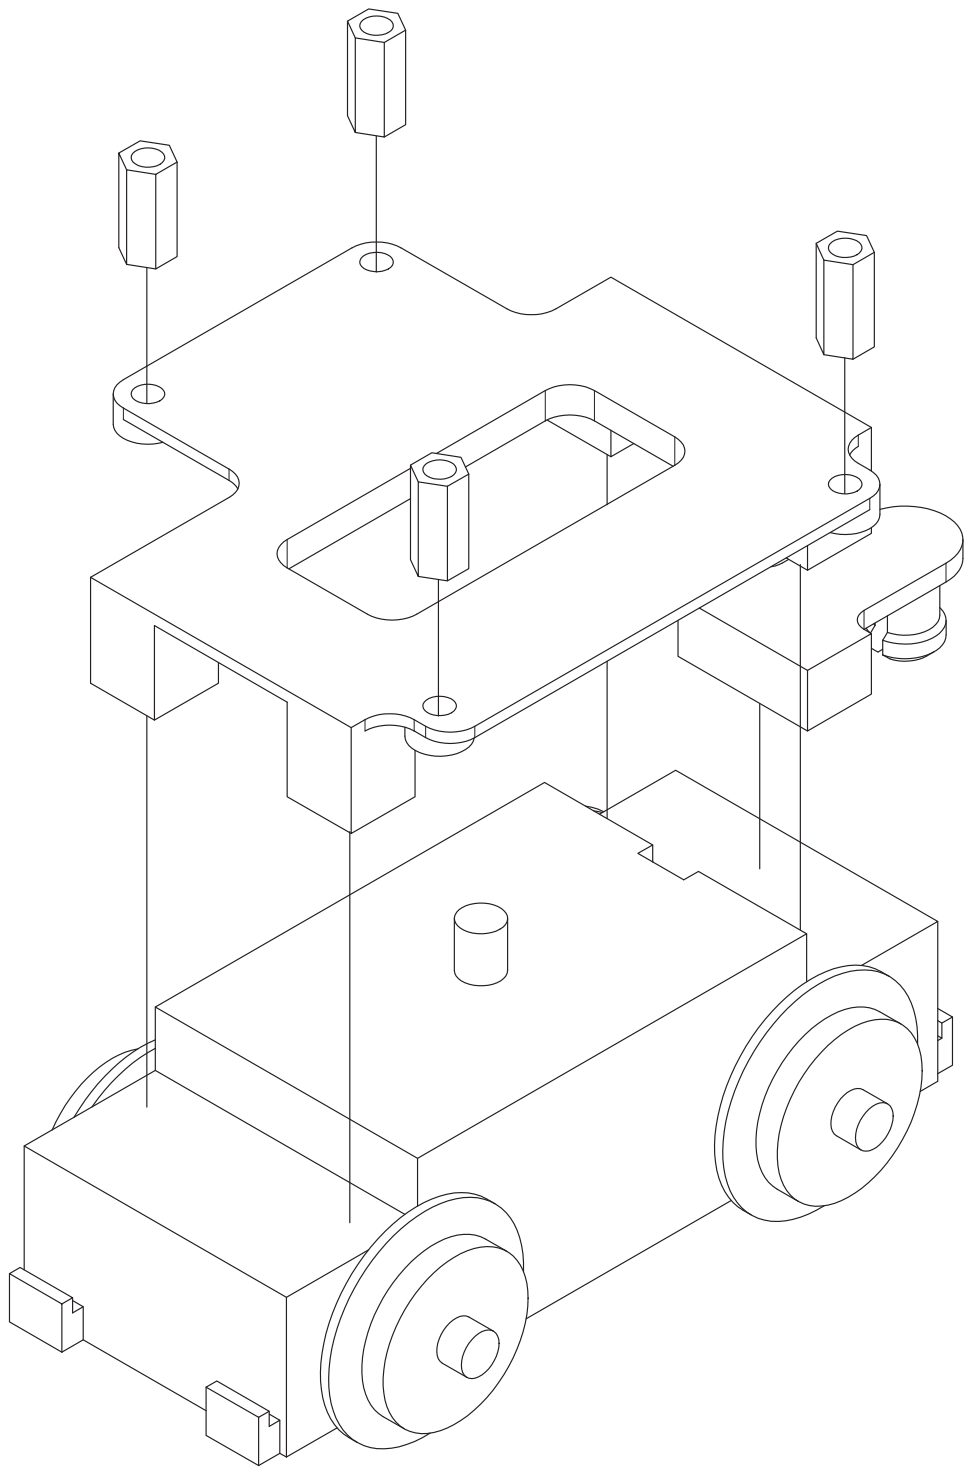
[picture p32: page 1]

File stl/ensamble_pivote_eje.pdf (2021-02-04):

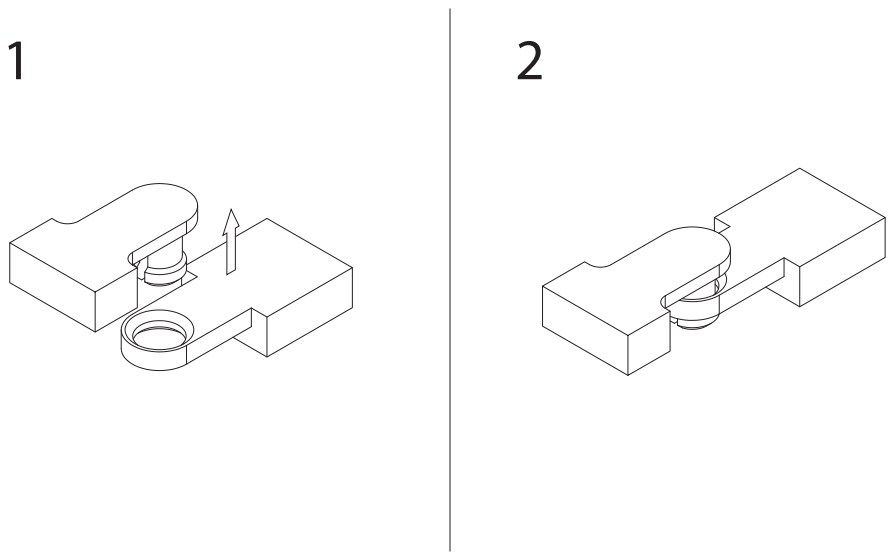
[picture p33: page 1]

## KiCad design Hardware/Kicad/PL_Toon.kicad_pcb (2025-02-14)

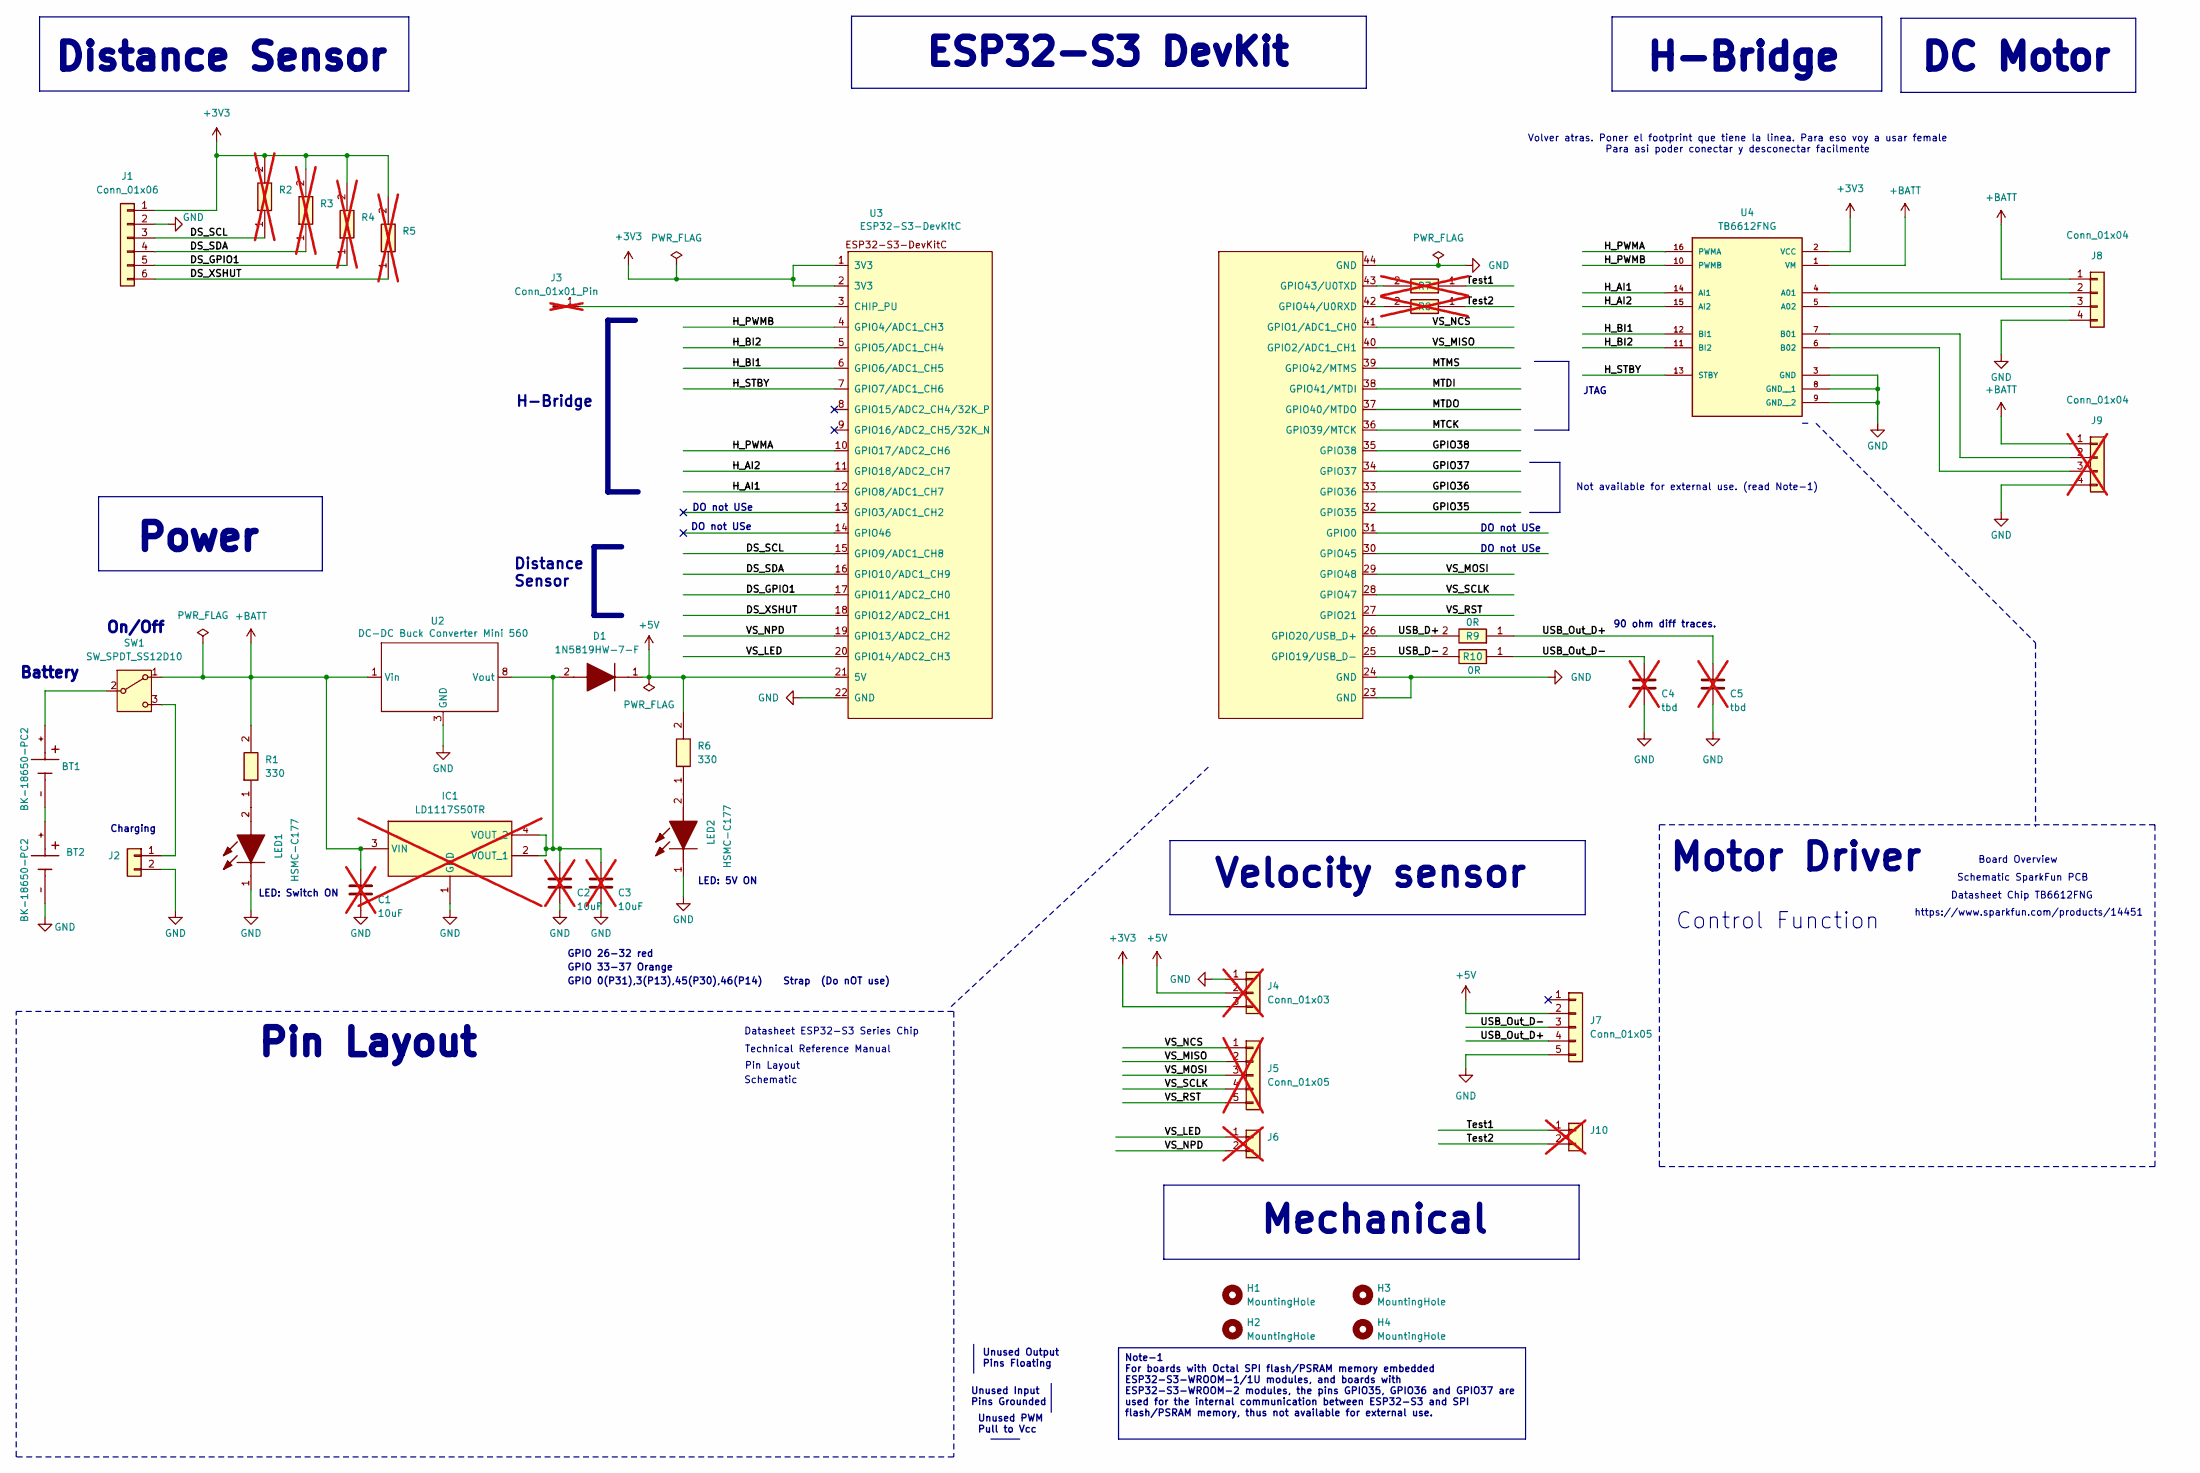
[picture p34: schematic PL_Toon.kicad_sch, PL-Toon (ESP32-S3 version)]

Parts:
BT1, BT2: BK-18650-PC2; BAT_BK-18650-PC2; PARTREV F
C1, C2, C3: 10uF; C_1206_3216Metric; not fitted
C4, C5: tbd; C_1206_3216Metric; not fitted
D1: 1N5819HW-7-F; D_SOD-123; Mouser Part Number 621-1N5819HW-F
H1, H2, H3, H4: MountingHole; MountingHole_3.2mm_M3
IC1: LD1117S50TR; SOT230P700X190-4N; Mouser Part Number 511-LD1117S50; not fitted
J1: Conn_01x06; JST_PH_B6B-PH-K_1x06_P2.00mm_Vertical
J2: Conn_01x02; JST_PH_B2B-PH-K_1x02_P2.00mm_Vertical
J3: Conn_01x01_Pin; PinHeader_1x01_P2.54mm_Vertical; not fitted
J4: Conn_01x03; JST_PH_B3B-PH-K_1x03_P2.00mm_Vertical; not fitted
J5: Conn_01x05; JST_PH_B5B-PH-K_1x05_P2.00mm_Vertical; not fitted
J6, J10: Conn_01x02; JST_PH_B2B-PH-K_1x02_P2.00mm_Vertical; not fitted
J7: Conn_01x05; JST_PH_B5B-PH-K_1x05_P2.00mm_Vertical
J8: Conn_01x04; JST_PH_B4B-PH-K_1x04_P2.00mm_Vertical
J9: Conn_01x04; JST_PH_B4B-PH-K_1x04_P2.00mm_Vertical; not fitted
LED1, LED2: HSMC-C177; LED_1206_3216Metric_Pad1.42x1.75mm_HandSolder; Mouser Part Number 630-HSMC-C177
R1, R6: 330; R_1206_3216Metric_Pad1.30x1.75mm_HandSolder
R2, R3, R4, R5, R7, R8: R_1206_3216Metric_Pad1.30x1.75mm_HandSolder; not fitted
R9, R10: 0R; R_1206_3216Metric_Pad1.30x1.75mm_HandSolder
SW1: SW_SPDT_SS12D10; SS12D10
U2: DC-DC Buck Converter Mini 560; Mini560
U3: ESP32-S3-DevKitC
U4: TB6612FNG; MODULE_ROB-14450; PARTREV 11-13-17

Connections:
+3V3: J1.1, J4.3, R2.2, R3.2, R4.2, R5.2, U3.1 (3V3), U3.2 (3V3), U4.2 (VCC)
+5V: D1.1 (K), J4.2, J7.2, R6.2, U3.21 (5V)
+BATT: C1.1, IC1.3 (VIN), J8.1, J9.1, R1.2, SW1.1 (A), U2.1 (Vin), U2.2 (Vin), U4.1 (VM)
/DS_GPIO1: J1.5, R4.1, U3.17 (GPIO11/ADC2_CH0)
/DS_SCL: J1.3, R2.1, U3.15 (GPIO9/ADC1_CH8)
/DS_SDA: J1.4, R3.1, U3.16 (GPIO10/ADC1_CH9)
/DS_XSHUT: J1.6, R5.1, U3.18 (GPIO12/ADC2_CH1)
/GPIO35: U3.32 (GPIO35)
/GPIO36: U3.33 (GPIO36)
/GPIO37: U3.34 (GPIO37)
/GPIO38: U3.35 (GPIO38)
/H_AI1: U3.12 (GPIO8/ADC1_CH7), U4.14 (AI1)
/H_AI2: U3.11 (GPIO18/ADC2_CH7), U4.15 (AI2)
/H_BI1: U3.6 (GPIO6/ADC1_CH5), U4.12 (BI1)
/H_BI2: U3.5 (GPIO5/ADC1_CH4), U4.11 (BI2)
/H_PWMA: U3.10 (GPIO17/ADC2_CH6), U4.16 (PWMA)
/H_PWMB: U3.4 (GPIO4/ADC1_CH3), U4.10 (PWMB)
/H_STBY: U3.7 (GPIO7/ADC1_CH6), U4.13 (STBY)
/MTCK: U3.36 (GPIO39/MTCK)
/MTDI: U3.38 (GPIO41/MTDI)
/MTDO: U3.37 (GPIO40/MTDO)
/MTMS: U3.39 (GPIO42/MTMS)
/Test1: J10.1, R7.1
/Test2: J10.2, R8.1
/USB_D+: R9.2, U3.26 (GPIO20/USB_D+)
/USB_D-: R10.2, U3.25 (GPIO19/USB_D-)
/USB_Out_D+: C5.1, J7.4, R9.1
/USB_Out_D-: C4.1, J7.3, R10.1
/VS_LED: J6.1, U3.20 (GPIO14/ADC2_CH3)
/VS_MISO: J5.2, U3.40 (GPIO2/ADC1_CH1)
/VS_MOSI: J5.3, U3.29 (GPIO48)
/VS_NCS: J5.1, U3.41 (GPIO1/ADC1_CH0)
/VS_NPD: J6.2, U3.19 (GPIO13/ADC2_CH2)
/VS_RST: J5.5, U3.27 (GPIO21)
/VS_SCLK: J5.4, U3.28 (GPIO47)
GND: BT2.-, C1.2, C2.2, C3.2, C4.2, C5.2, IC1.1 (GND), J1.2, J2.2, J4.1, J7.5, J8.4, J9.4, LED1.1 (K), LED2.1 (K), U2.3 (GND), U2.4 (GND), U2.5 (GND), U2.6 (GND), U3.22 (GND), U3.23 (GND), U3.24 (GND), U3.44 (GND), U4.3 (GND), U4.8 (GND__1), U4.9 (GND__2)
unnamed: BT1.-, BT2.+
unnamed: C2.1, C3.1, D1.2 (A), IC1.2 (VOUT_1), IC1.4 (VOUT_2), U2.7 (Vout), U2.8 (Vout)
unnamed: J2.1, SW1.3 (C)
unnamed: J3.1, U3.3 (CHIP_PU)
unnamed: J8.2, U4.4 (A01)
unnamed: J8.3, U4.5 (A02)
unnamed: J9.2, U4.7 (B01)
unnamed: J9.3, U4.6 (B02)
unnamed: LED1.2 (A), R1.1
unnamed: LED2.2 (A), R6.1
unnamed: BT1.+, SW1.2 (B)
unnamed: R7.2, U3.43 (GPIO43/U0TXD)
unnamed: R8.2, U3.42 (GPIO44/U0RXD)

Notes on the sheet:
Note-1 For boards with Octal SPI flash/PSRAM memory embedded ESP32-S3-WROOM-1/1U modules, and boards with ESP32-S3-WROOM-2 modules, the pins GPIO35, GPIO36 and GPIO37 are used for the internal communication between ESP32-S3 and SPI flash/PSRAM memory, thus not available for external use.
Pin Layout
Velocity sensor
Mechanical
https://www.sparkfun.com/products/14451
Unused PWM Pull to Vcc
LED: 5V ON
GPIO 0(P31),3(P13),45(P30),46(P14) Strap (Do nOT use)
Battery
Distance Sensor
Unused Input Pins Grounded
90 ohm diff traces.
H-Bridge
Pin Layout
Motor Driver
GPIO 26-32 red
Technical Reference Manual
ESP32-S3 DevKit
Schematic
GPIO 33-37 Orange
DO not USe
Unused Output Pins Floating
Control Function
Charging
Schematic SparkFun PCB
Not available for external use. (read Note-1)
Datasheet Chip TB6612FNG
H-Bridge
Distance Sensor
Board Overview
DC Motor
Datasheet ESP32-S3 Series Chip
Power
LED: Switch ON
On/Off
Volver atras. Poner el footprint que tiene la linea. Para eso voy a usar female Para asi poder conectar y desconectar facilmente
JTAG

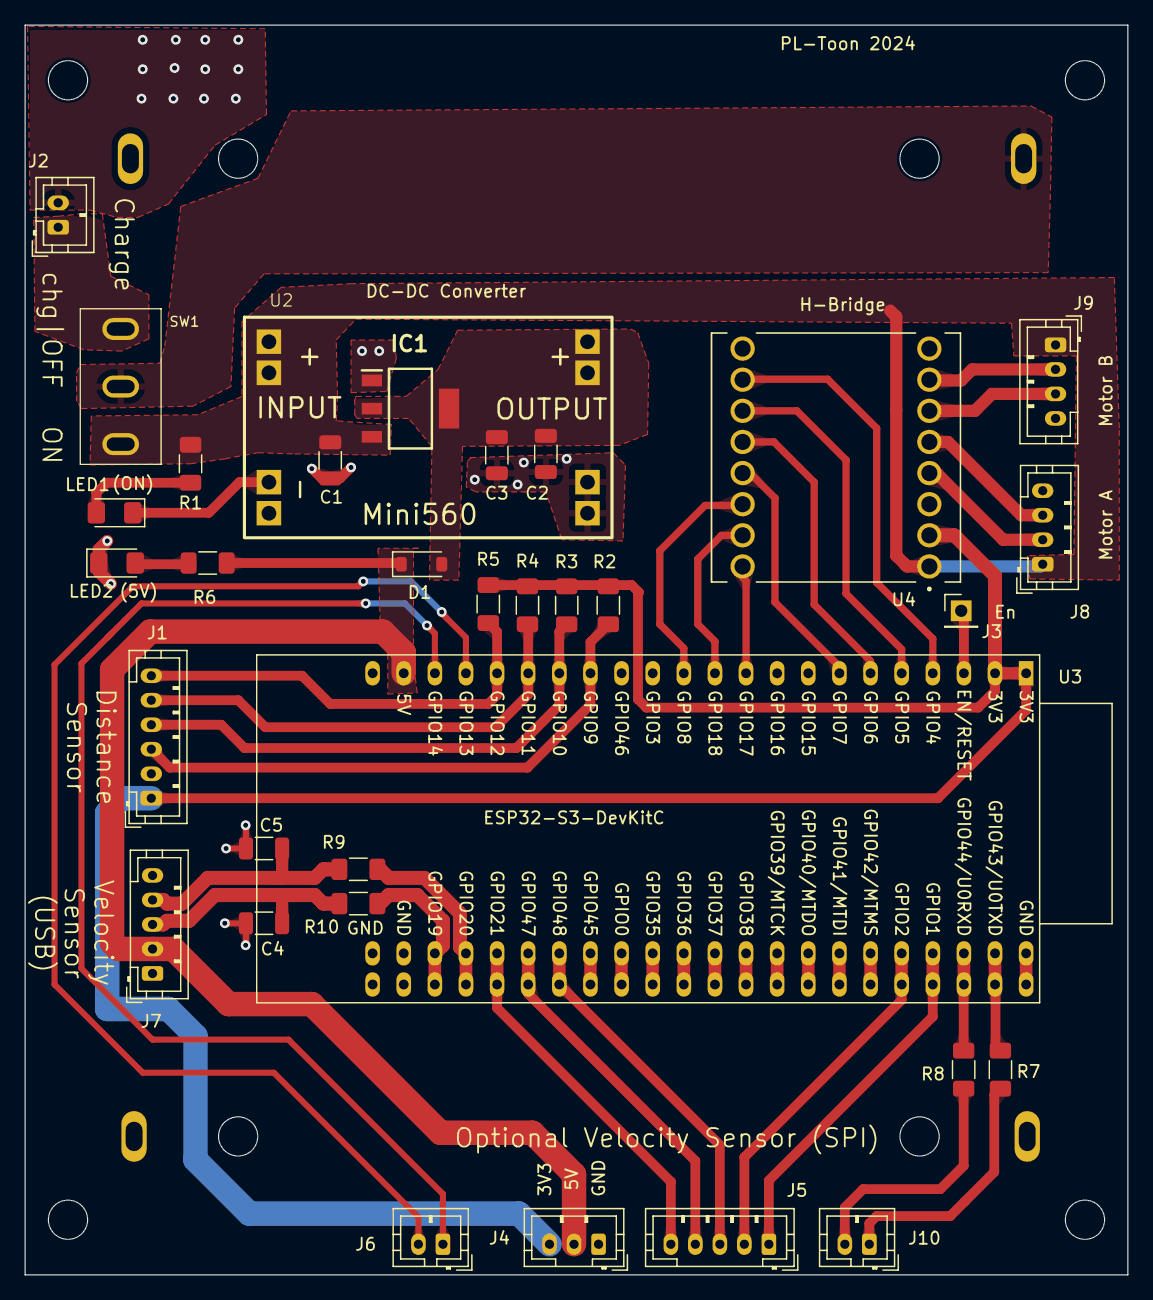
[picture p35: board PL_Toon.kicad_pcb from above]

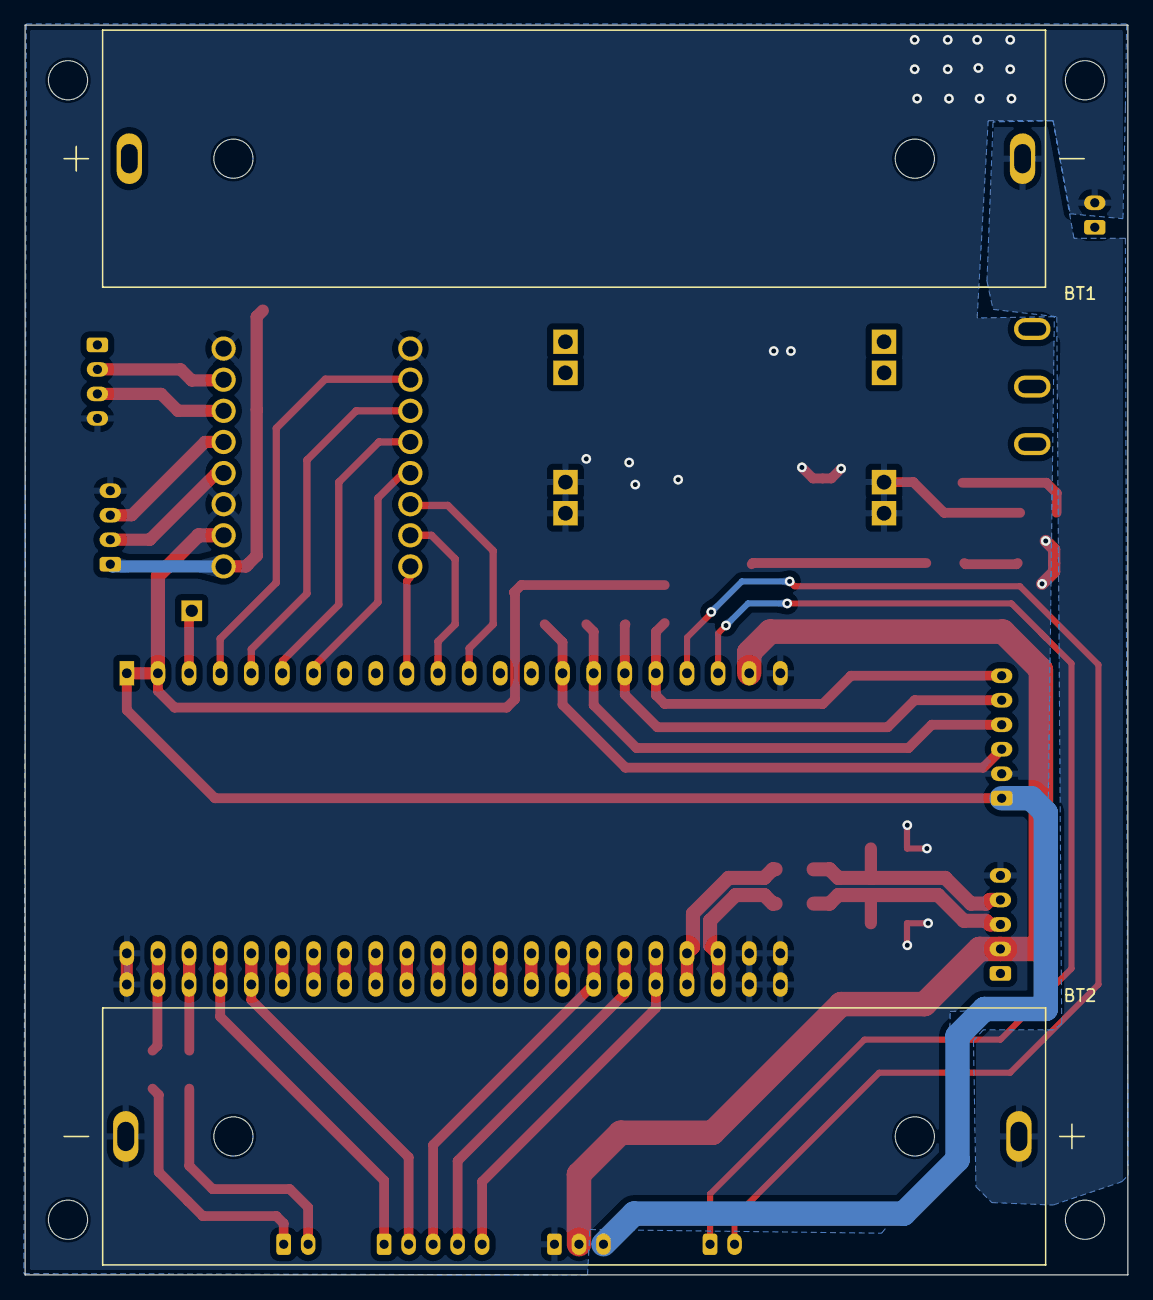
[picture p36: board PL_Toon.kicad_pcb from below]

Board: 2 copper layers, 90.0 x 102.0 mm, 39 parts (2 on the bottom side), 41 nets.

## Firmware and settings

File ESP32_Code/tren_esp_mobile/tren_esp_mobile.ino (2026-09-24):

/*
 * MOBILE VERSION - Train Control Firmware with WiFi AP + WebSocket Dashboard
 * v2.4: PID Control, Step Response, Deadband Calibration
 *
 * Creates a WiFi Access Point (TrenCE-<trainID>) and serves a mobile web
 * dashboard at 192.168.4.1. Communication via WebSocket (JSON).
 *
 * v2.4 changes (re-validation required: control timing changed):
 * - Non-blocking VL53L0X read (data-ready poll) replaces the blocking
 *   2 x delay(21) read; the PID loop now genuinely runs at the 50 ms
 *   sample time (v2.3 realized ~95 ms, so displayed Ki/Kd were rescaled).
 * - All shared doubles (gains, reference, step/deadband params) are
 *   written under a spinlock; start/stop are deferred to loop(), so the
 *   WebSocket task never mutates PID/motor state mid-control-pass.
 * - LittleFS no longer auto-formats on mount failure, and a missing
 *   /index.html is fatal at boot (was: silent empty dashboard).
 * - WebSocket JSON parsed with an explicit length (no out-of-bounds
 *   null terminator); start requires an exact mode string.
 * - Step duration is anchored when the step is applied (warm-up and
 *   baseline no longer eat into the commanded duration).
 * - Acks go only to the requesting client (data frames still broadcast).
 * - GET /heap returns free-heap telemetry; info frame carries "heap".
 * - Removed dead code (etha/ponderado/old_d/no-op EMA blend).
 *
 * EXPERIMENT MODES:
 * - PID Control:          Closed-loop distance tracking with Kp/Ki/Kd tuning
 * - Step Response:        Open-loop motor step with configurable amplitude/duration
 * - Deadband Calibration: Auto-detects minimum PWM to move the train
 *
 * CONFIGURATION COMMANDS (Serial, 115200 baud):
 * - SET_TRAIN:trainID:port   - Configure train ID (e.g., SET_TRAIN:trainA:5555)
 * - SET_MOTOR_INV:0|1        - Set motor direction inversion for this train
 * - GET_TRAIN                - Display current configuration
 * - RESET_TRAIN              - Clear configuration and restart
 * - STATUS                   - Show connection status
 *
 * LED FEEDBACK:
 * - Fast blink (200ms)  : Not configured, waiting for setup
 * - Slow blink (1s)     : Configured, starting AP
 * - Solid ON            : AP active, web server running
 * - 3 quick flashes     : Configuration saved successfully
 *
 * WebSocket Protocol (JSON):
 * - ESP→Phone data (PID):      {"t":"d","m":"pid","ts":1234,"d":15.2,"r":10.0,"e":-5.2,"kp":2.5,"ki":0.8,"kd":1.2,"u":127}
 * - ESP→Phone data (Step):     {"t":"d","m":"step","ts":1234,"d":15.2,"pwm":100,"amp":0.5,"dir":1}
 * - ESP→Phone data (Deadband): {"t":"d","m":"deadband","ts":1234,"d":15.2,"pwm":50,"d0":15.0,"motion":0}
 * - Every "t":"d" frame also carries "seq": a per-boot monotonic uint32,
 *   incremented once per frame sent (v2.5; lets the dashboard count
 *   server-side frame drops within one connected stretch)
 * - Phone→ESP cmd:             {"t":"cmd","c":"kp","v":2.5}
 * - Phone→ESP start:           {"t":"cmd","c":"start","m":"pid"}
 * - ESP→Phone ack:             {"t":"ack","c":"kp","v":2.5}
 * - ESP→Phone status:          {"t":"status","mode":"pid","active":true}
 * - ESP→Phone info:            {"t":"info","id":"trainA","ip":"192.168.4.1","ap":"TrenCE-trainA","fw":"2.3-mobile"}
 *
 * Dependencies (Arduino Library Manager):
 * - ESPAsyncWebServer by mathieucarbou (v3.0+)
 * - AsyncTCP by mathieucarbou
 * - ArduinoJson by Benoit Blanchon (v7.x)
 * - PID_v1_bc
 * - VL53L0X by Pololu
 * - LittleFS (built into ESP32 core)
 */

#include <PID_v1_bc.h>
#include <WiFi.h>
#include <Wire.h>
#include <VL53L0X.h>
#include <esp_wifi.h>
#include <Preferences.h>
#include <LittleFS.h>
#include <ESPAsyncWebServer.h>
#include <ArduinoJson.h>
#include <DNSServer.h>

// =============================================================================
// Firmware Version
// =============================================================================
#define FW_VERSION "2.5.0-mobile"   // 2.5.0: "seq" field in every data frame (link-quality logging); 2.4.2: step-mode brake phase

// =============================================================================
// EEPROM Configuration Storage
// =============================================================================
Preferences preferences;

// Configuration variables (loaded from EEPROM)
String train_id = "";
int configured_udp_port = 5555;  // Kept for backward compat / serial config
bool is_configured = false;
bool motor_inverted = false;

// LED pin for status feedback
#define STATUS_LED 2

// Configuration mode variables
unsigned long last_led_toggle = 0;
int led_blink_interval = 200;
bool led_state = false;

// =============================================================================
// WiFi AP Configuration
// =============================================================================
String ap_ssid = "";           // Generated from train_id: "TrenCE-trainA"
const char* ap_password = "train123";  // AP password
IPAddress ap_ip(192, 168, 4, 1);
IPAddress ap_gateway(192, 168, 4, 1);
IPAddress ap_subnet(255, 255, 255, 0);

// =============================================================================
// Web Server + WebSocket
// =============================================================================
AsyncWebServer server(80);
AsyncWebSocket ws("/ws");

// Wildcard DNS: any typed hostname resolves to the AP address. The OS
// connectivity probes are answered as "online" (see setup_webserver) so the
// dashboard opens in the normal browser, NOT in the captive-portal sign-in
// WebView (which blocks file downloads). There is no captive auto-open by
// design; the student scans a QR code or types the fixed address.
DNSServer dnsServer;
const byte DNS_PORT = 53;

// WebSocket state
bool ws_client_connected = false;
uint32_t ws_packet_count = 0;
// Per-boot monotonic sequence number, incremented once per data frame sent
// (never reset between experiments; the dashboard uses gaps to count
// server-side frame drops). Only touched from loop() context.
uint32_t ws_seq = 0;

// =============================================================================
// Cross-core command / parameter handoff
// =============================================================================
// WebSocket callbacks run in the AsyncTCP task (typically the other core);
// the control loop runs in loop(). Aligned 32-bit ints/bools are atomic on
// the ESP32, but a double is written in two 32-bit steps, so every double
// shared between the two contexts is accessed under paramMux. Start/stop
// requests are staged here and applied in loop(), so mode setup and
// PID/motor calls never run concurrently with a control pass.
portMUX_TYPE paramMux = portMUX_INITIALIZER_UNLOCKED;
volatile int pending_start_mode = -1;   // -1 = none, else PID/STEP/DEADBAND_MODE
volatile bool pending_stop = false;

// =============================================================================
// Experiment Mode
// =============================================================================
#define PID_MODE 0
#define STEP_MODE 1
#define DEADBAND_MODE 2
int currentExperimentMode = PID_MODE;
bool experimentActive = false;

// =============================================================================
// Motor Configuration
// =============================================================================
const int STBY = 7;
const int Control_fwd = 8;
const int Control_back = 18;
const int Control_v = 17;
int MotorSpeed = 0;

int PIDMotorDirection = 1;
int StepMotorDirection = 1;
int DeadbandMotorDirection = 1;
int MotorDirection = 1;

// =============================================================================
// ToF Sensor
// =============================================================================
VL53L0X SensorToF;
double medi = 0;        // filtered distance [cm]
double distancia = 25;

// Moving average filter (raw readings in mm). 6 taps at the ~24 ms sensor
// rate ≈ 144 ms window: the same 6-raw-sample depth the v2.3 pipeline had
// (2-read average + 3-tap MA at ~95 ms), at half the effective lag. With 3
// taps the ±0.3 cm single-read noise reached the PID and rattled u across
// the ±lim actuation threshold at steady state (measured 2026-07-03).
int arrNumbers[6] = {0};
int pos = 0;
long sum = 0;
int len = sizeof(arrNumbers) / sizeof(int);

// Non-blocking sensor service state
const uint32_t TOF_POLL_MS = 5;   // min interval between data-ready polls
uint32_t last_tof_poll = 0;
uint16_t last_range_mm = 250;     // reused on an I2C glitch (65535 read)
uint32_t last_fresh_ms = 0;       // last time a fresh sample was absorbed

// =============================================================================
// PID Mode Variables
// =============================================================================
double x_ref = 10;
double error_distancia = 0;
double u_distancia = 0;
double rf = 0;                 // PID setpoint: input is the error, setpoint 0
double Kp = 0, Ki = 0, Kd = 0;
int SampleTime = 50;
int umin = -1024, umax = 1024;
int deadband = 50;
int lim = 10;
bool flag_pid = true;
uint32_t tiempo_inicial_pid = 0;
volatile bool pid_params_changed = false;
uint32_t pid_lost_next_send = 0;   // paces telemetry while the target is lost
const uint32_t TOF_STALE_MS = 500; // no fresh sample for this long -> stop

// Sensor warm-up for PID mode (must exceed the moving-average depth, so the
// filter is full before control starts)
const int PID_WARMUP_SAMPLES = 8;
int pidWarmupCounter = 0;

PID myPID(&error_distancia, &u_distancia, &rf, Kp, Ki, Kd, DIRECT);

// =============================================================================
// Step Response Mode Variables
// =============================================================================
double v_batt = 8.4;
double StepAmplitude = 0;
uint32_t StepTime = 0;             // end time; anchored when the step is applied
uint32_t StepTimeDuration = 0;
uint32_t tiempo_inicial_step = 0;
bool flag_step = true;
const uint32_t STEP_TICK_MS = 50;  // sampling/actuation period of step mode
uint32_t step_next_tick = 0;
const int STEP_WARMUP_SAMPLES = 5;
const int STEP_BASELINE_SAMPLES = 3;
int stepWarmupCounter = 0;
int stepBaselineCounter = 0;
double appliedStepValue = 0.0;
// Optional brake phase after the drive window (direction-asymmetry diagnostics).
// 0 = none (legacy stop = TB6612 short brake at PWM 0), 1 = coast (high-Z),
// 2 = opposite torque at BrakePwm. Duration BrakeMs, then normal stop.
int BrakeMode = 0;
int BrakePwm = 400;
uint32_t BrakeMs = 800;
bool stepBraking = false;
uint32_t brakeUntil = 0;

// =============================================================================
// Deadband Calibration Mode Variables
// =============================================================================
bool flag_deadband = true;
uint32_t tiempo_inicial_deadband = 0;
int calibrated_deadband = 0;
double initial_distance = 0;
int pwm_increment = 1;
int pwm_delay = 40;
double motion_threshold = 0.08;
int max_pwm_test = 800;
bool motion_detected = false;
int consecutive_motion_count = 0;
const int MOTION_CONFIRM_COUNT = 2;

// =============================================================================
// Configuration Mode Functions
// =============================================================================

void loadConfiguration() {
  preferences.begin("train-config", false);
  is_configured = preferences.getBool("configured", false);
  motor_inverted = preferences.getBool("motor_inv", false);

  if (is_configured) {
    train_id = preferences.getString("train_id", "");
    configured_udp_port = preferences.getInt("udp_port", 5555);

    Serial.println("Configuration loaded from EEPROM:");
    Serial.println("  Train ID: " + train_id);
    Serial.println("  UDP Port: " + String(configured_udp_port));
    Serial.println("  Motor inverted: " + String(motor_inverted ? "YES" : "NO"));
  }

  preferences.end();
}

void saveConfiguration(String id, int port) {
  preferences.begin("train-config", false);
  preferences.putString("train_id", id);
  preferences.putInt("udp_port", port);
  preferences.putBool("configured", true);
  preferences.end();

  Serial.println("\nConfiguration saved to EEPROM!");
  Serial.println("  Train ID: " + id);
  Serial.println("  UDP Port: " + String(port));

  blinkLED(3, 150);

  Serial.println("\nRebooting...");
  delay(1000);
  ESP.restart();
}

void saveMotorInversion(bool inverted) {
  preferences.begin("train-config", false);
  preferences.putBool("motor_inv", inverted);
  preferences.end();

  motor_inverted = inverted;

  Serial.println("\nMotor direction configuration saved!");
  Serial.println("  Motor inverted: " + String(motor_inverted ? "YES" : "NO"));
  Serial.println("  Use Step mode Forward to verify physical direction.");
}

void resetConfiguration() {
  preferences.begin("train-config", false);
  preferences.clear();
  preferences.end();

  Serial.println("\nConfiguration cleared!");
  Serial.println("Rebooting to config mode...");
  delay(1000);
  ESP.restart();
}

void printConfiguration() {
  Serial.println("\n========================================");
  Serial.println("CURRENT CONFIGURATION");
  Serial.println("========================================");

  if (is_configured) {
    Serial.println("Status: CONFIGURED");
    Serial.println("Train ID: " + train_id);
    Serial.println("AP SSID: " + ap_ssid);
    Serial.println("AP IP: 192.168.4.1");
    Serial.println("Motor inverted: " + String(motor_inverted ? "YES" : "NO"));
    Serial.println("WebSocket clients: " + String(ws.count()));
    Serial.println("Experiment active: " + String(experimentActive ? "YES" : "NO"));
  } else {
    Serial.println("Status: NOT CONFIGURED");
    Serial.println("Motor inverted: " + String(motor_inverted ? "YES" : "NO"));
    Serial.println("Use: SET_TRAIN:trainID:port");
  }

  Serial.println("========================================\n");
}

void blinkLED(int times, int delayMs) {
  for (int i = 0; i < times; i++) {
    digitalWrite(STATUS_LED, HIGH);
    delay(delayMs);
    digitalWrite(STATUS_LED, LOW);
    delay(delayMs);
  }
}
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
void loop() {
  // Always check for serial config commands
  checkSerialConfig();

  // Wildcard DNS (typed hostnames resolve to the dashboard)
  dnsServer.processNextRequest();

  // Update status LED
  updateStatusLED();

  // Clean up WebSocket clients
  ws.cleanupClients();

  // Apply start/stop requests staged by the WebSocket task
  if (pending_stop) {
    pending_stop = false;
    pending_start_mode = -1;   // a stop also cancels a queued start
    stop_experiment("requested");
    ws_send_status_all();
  }
  int requested = pending_start_mode;
  if (requested >= 0) {
    pending_start_mode = -1;
    start_experiment(requested);
    ws_send_status_all();
  }

  // Run experiment if active
  if (experimentActive) {
    switch (currentExperimentMode) {
      case PID_MODE:
        loop_pid_experiment();
        break;
      case STEP_MODE:
        loop_step_experiment();
        break;
      case DEADBAND_MODE:
        loop_deadband_experiment();
        break;
    }
  } else {
    // Idle mode - motor off
    MotorSpeed = 0;
    SetMotorControl();
    delay(20);
  }
}

// =============================================================================
// PID Experiment Loop
// =============================================================================

// Non-blocking PID pass. loop() calls this every few milliseconds; the
// sensor is serviced opportunistically (fresh sample every ~24 ms at the
// 22 ms timing budget) and the PID library fires on its own 50 ms clock
// (Compute() returns true), so the realized control period matches
// SampleTime. Actuation and telemetry happen only on PID ticks (20 Hz).
void loop_pid_experiment() {
  if (flag_pid == false) {
    flag_pid = true;
    pidWarmupCounter = 0;
    ws_packet_count = 0;
    pid_lost_next_send = millis();
    last_fresh_ms = millis();
    Serial.println("[PID] Experiment started!");
    Serial.print("  Sensor warm-up: "); Serial.print(PID_WARMUP_SAMPLES); Serial.println(" samples");
    myPID.SetMode(MANUAL);
    PIDMotorDirection = 1;
  }

  bool fresh = tof_service();

  // SENSOR WARM-UP: discard the first N fresh samples, motor off
  if (pidWarmupCounter < PID_WARMUP_SAMPLES) {
    if (fresh) {
      pidWarmupCounter++;
      if (pidWarmupCounter == PID_WARMUP_SAMPLES) {
        // Seed the PID input before AUTOMATIC for a bumpless start
        distancia = medi;
        portENTER_CRITICAL(&paramMux);
        double r = x_ref;
        portEXIT_CRITICAL(&paramMux);
        error_distancia = r - distancia;
        myPID.SetMode(AUTOMATIC);
        Serial.println("[PID] Warm-up complete, starting control...");
      }
    }
    MotorSpeed = 0;
    MotorDirection = PIDMotorDirection;
    SetMotorControl();
    return;
  }

  if (pid_params_changed) {
    portENTER_CRITICAL(&paramMux);
    double kp = Kp, ki = Ki, kd = Kd;
    pid_params_changed = false;
    portEXIT_CRITICAL(&paramMux);
    myPID.SetTunings(kp, ki, kd);
    Serial.printf("[PID] Params updated - Kp:%.2f Ki:%.2f Kd:%.2f\n", kp, ki, kd);
  }

  distancia = medi;
  portENTER_CRITICAL(&paramMux);
  double r = x_ref;
  portEXIT_CRITICAL(&paramMux);
  error_distancia = r - distancia;

  // Target lost (out of range) or sensor stale: stop and skip the PID until
  // it returns, so no integral action accumulates against a phantom error.
  if (distancia > 200 || millis() - last_fresh_ms > TOF_STALE_MS) {
    MotorSpeed = 0;
    MotorDirection = PIDMotorDirection;
    SetMotorControl();
    if ((int32_t)(millis() - pid_lost_next_send) >= 0) {
      pid_lost_next_send = millis() + (uint32_t)SampleTime;
      ws_send_pid_data();
    }
    return;
  }

  if (myPID.Compute()) {   // true once per SampleTime
    double u = u_distancia;

    if (u > lim) {
      PIDMotorDirection = 1;
      MotorSpeed = constrain(int(u + deadband), 0, 1023);
    }
    else if (u < -lim) {
      PIDMotorDirection = 0;
      MotorSpeed = constrain(int(-u + deadband), 0, 1023);
    }
    else {
      MotorSpeed = 0;
    }

    MotorDirection = PIDMotorDirection;
    SetMotorControl();
    ws_send_pid_data();
  }
}

// =============================================================================
// Step Response Experiment Loop
// =============================================================================

// Non-blocking step pass, paced at STEP_TICK_MS. The commanded duration is
// anchored when the step is actually applied, so warm-up and baseline no
// longer eat into it.
void loop_step_experiment() {
  if (flag_step == false) {
    flag_step = true;
    Serial.println("[STEP] Experiment started!");
    Serial.print("  Duration: "); Serial.print(StepTimeDuration / 1000.0); Serial.println("s");
    Serial.print("  Direction: "); Serial.println(StepMotorDirection ? "Forward" : "Reverse");

    StepTime = 0;   // set when the step is applied
    stepWarmupCounter = 0;
    stepBaselineCounter = 0;
    appliedStepValue = 0.0;
    stepBraking = false;
    ws_packet_count = 0;
    step_next_tick = millis();
    last_fresh_ms = millis();
  }

  tof_service();

  uint32_t now = millis();
  if ((int32_t)(now - step_next_tick) < 0) return;
  step_next_tick += STEP_TICK_MS;

  // Brake phase (replaces the normal stop when BrakeMode > 0): apply the
  // configured stop mode for BrakeMs, streaming telemetry, then stop.
  if (stepBraking) {
    if (BrakeMode == 1) {
      MotorSpeed = 0;
      MotorCoast();
    } else {
      MotorDirection = !StepMotorDirection;
      MotorSpeed = BrakePwm;
      SetMotorControl();
    }
    ws_send_step_data();
    if ((int32_t)(now - brakeUntil) >= 0) {
      Serial.println("[STEP] Brake phase complete");
      stop_experiment("step complete");
      ws_send_status_all();
    }
    return;
  }

  // Three-phase: WARMUP -> BASELINE -> STEP APPLIED
  if (stepWarmupCounter < STEP_WARMUP_SAMPLES) {
    stepWarmupCounter++;
    MotorSpeed = 0;
    appliedStepValue = 0.0;
    MotorDirection = StepMotorDirection;
    SetMotorControl();
    if (stepWarmupCounter == STEP_WARMUP_SAMPLES) {
      Serial.println("[STEP] Warm-up complete, collecting baseline...");
    }
    return;
  }
  else if (stepBaselineCounter < STEP_BASELINE_SAMPLES) {
    stepBaselineCounter++;
    MotorSpeed = 0;
    appliedStepValue = 0.0;
    if (stepBaselineCounter == STEP_BASELINE_SAMPLES) {
      Serial.println("[STEP] Baseline collected, applying step!");
    }
  }
  else {
    portENTER_CRITICAL(&paramMux);
    double amp = StepAmplitude, vb = v_batt;
    portEXIT_CRITICAL(&paramMux);
    if (vb < 1.0) vb = 1.0;   // guard the division

    if (appliedStepValue == 0.0) {
      StepTime = now + StepTimeDuration;   // anchor duration at application
      Serial.println("[STEP] Step applied");
    }
    appliedStepValue = amp;
    MotorSpeed = constrain((int)(amp * 1023.0 / vb), 0, 1023);
  }

  MotorDirection = StepMotorDirection;
  SetMotorControl();
  ws_send_step_data();

  if (StepTime > 0 && (int32_t)(now - StepTime) >= 0) {
    if (BrakeMode > 0) {
      stepBraking = true;
      brakeUntil = now + BrakeMs;
      appliedStepValue = 0.0;
      Serial.printf("[STEP] Brake phase: mode %d, pwm %d, %u ms\n", BrakeMode, BrakePwm, BrakeMs);
      return;
    }
    Serial.println("[STEP] Experiment complete");
    stop_experiment("step complete");
    ws_send_status_all();
  }
}

// =============================================================================
// Deadband Calibration Experiment Loop
// =============================================================================
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

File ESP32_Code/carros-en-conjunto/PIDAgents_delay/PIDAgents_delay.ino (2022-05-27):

/*
 * Last Modified: 04-19-2022
 */

#include <PID_v1.h>
#include <WiFi.h>
#include <PubSubClient.h>
#include "SPI.h"
#include <Wire.h>   // ???
#include <VL53L0X.h>  // Pololu 1.0.2
#include <esp_wifi_types.h>
#include <esp_wifi_internal.h>
#include <esp_wifi.h>
#include <esp_now.h>
#include <WiFiUDP.h>
#include "math.h"

#include "KickFiltersRT.h"

#define DATARATE        WIFI_PHY_RATE_6M   // Para cambiar el bitrate de ESP-NOW a 24Mbps
#define CHANNEL         3                   // Canal WiFi
#define DELAY_CAM		800

#define ONBOARD_LED  2

#define PAYLOAD_SIZE	6     // numero de doubles para monitoreo
#define Ts            	20    // tiempo en ms

#define n_carro 		3     // lider = 0
#define delay_size		40	// delay_size * Ts (ms) {ej. 10*50 = 500 ms}



////////////////////////////////////////////
///////////////////////////////////////////
String carro = "carro" + String(random(100));
//const char carro[] = "carroD2";
char treneserror[] = "trenes/carroD/error";
char trenesp[] = "trenes/carroD/p";
char trenesi[] = "trenes/carroD/i";
char trenesd[] = "trenes/carroD/d";
char trenesp_v[] = "trenes/carroD/p_v";
char trenesi_v[] = "trenes/carroD/i_v";
char trenesd_v[] = "trenes/carroD/d_v";
char trenesdesfase[] = "trenes/carroD/desfase";
char trenesestado[] = "trenes/estado/carroD";
char trenestest[] = "trenes/carroD/test";     // topic to send the data to analyze separated by "," (deprecated?)
char trenessampletime[] = "trenes/carroD/ts"; // topic to modify the PID sample time
char trenestransmision[] = "trenes/envio";    // topic to modify the transmission rate
int t_envio = 50;                             // default tx-rate;
///////////////////////////////////////////
///////////////////////////////////////////
/*---------------------------------------------------------------------*/
/*---------------------------------------------------------------------*/
typedef struct filterIIR {
	double x_vec[20];
	double y_vec[20];
	double b[20];
	double a[20];
	double G;
	int N;
	filterIIR(int N_points, double *b_coeff, double *a_coeff, double gain = 1){
		N = N_points;
		G = gain;
		bzero(x_vec, N*sizeof(double));
		bzero(y_vec, N*sizeof(double));
		bzero(b, N*sizeof(double));
		bzero(a, N*sizeof(double));
		if(b_coeff != NULL)
			memcpy(b, b_coeff, N*sizeof(double));
		if(a_coeff != NULL)
			memcpy(a, a_coeff, N*sizeof(double));
	}
	double filtering(double x){
		double ma = 0;
		double ar = 0;
		memmove(x_vec + 1, x_vec, (N-1)*sizeof(double));
		memmove(y_vec + 1, y_vec, (N-1)*sizeof(double));
		x_vec[0] = x;
		// moving average
		for(int n=0; n < N; n++){
			ma += b[n]*x_vec[n];
		}
		// auto regressive
		for(int n=1; n < N; n++){
			ar += (-1)*a[n]*y_vec[n];
		}
		y_vec[0] = ar + G*ma;
		return y_vec[0];
    }
} filterIIR;

typedef struct butterworth {
	double x_vec[3];
	double y_vec[3];
	double b[3];
	double a[3];
	double b_coeff[3];
	double a_coeff[3];
	double G;
	int N = 3;
	butterworth(double wn){
		G = wn*wn/(4/(PI*PI)-2*sqrt(2)*wn/PI+wn*wn);
		bzero(x_vec, N*sizeof(double));
		bzero(y_vec, N*sizeof(double));
		bzero(b, N*sizeof(double));
		bzero(a, N*sizeof(double));
		b_coeff[0] = 1;
		b_coeff[1] = 2;
		b_coeff[2] = 1;
		a_coeff[2] = 1;
		a_coeff[1] = (2*pow(wn,2)-8/(pow(M_PI,2)))/(4/(pow(M_PI,2))-2*sqrt(2)*wn/M_PI+pow(wn,2));
		a_coeff[0] = (4/(pow(M_PI,2))+2*sqrt(2)*wn/M_PI+pow(wn,2))/(4/(pow(M_PI,2))-2*sqrt(2)*wn/M_PI+pow(wn,2));
		double aa = M_PI;
		if(b_coeff != NULL)
		  memcpy(b, b_coeff, N*sizeof(double));
		if(a_coeff != NULL)
		  memcpy(a, a_coeff, N*sizeof(double));
	}
	double filtering(double x){
		double ma = 0;
		double ar = 0;
		memmove(x_vec + 1, x_vec, (N-1)*sizeof(double));
	    memmove(y_vec + 1, y_vec, (N-1)*sizeof(double));
		x_vec[0] = x;
	    // moving average
		for(int n=0; n < N; n++){
			ma += b[n]*x_vec[n];
	  	}
	    // auto regressive
		for(int n=1; n < N; n++){
			ar += (-1)*a[n]*y_vec[n];
	  	}
		y_vec[0] = (ar + G*ma)/a_coeff[0];
		return y_vec[0];
    }
} butterworth;



double Gain_butter = 0.0201;
double b_butter[3] = {1, 2, 1};
double a_butter[3] = {1, -1.5610, 0.6414};

//filterIIR filterPos(b_win, NULL, 5);
//filterIIR filterPos(3, b_butter, a_butter, Gain_butter);
butterworth filterPosB(0.15);
//filterIIR filterVel(b_hamm, NULL, 20);


///////////////////////////////////////
//     MQTT Configuration   ///////////
///////////////////////////////////////
const char* ssid = "fvp";
const char* password = "nomeacuerdo";
//const char* ssid = "GTD-3813230";
//const char* password= "g6yWsKswphfs";
//const char* ssid = "KATRINA";
//const char* password = "wlan70634f";
//const char* ssid = "MOVISTAR_7502";
//const char* password = "X27JgSvWteS2US4";

//const char* mqtt_server = "192.168.1.100";  // IP fvp
//const char* mqtt_server = "192.168.1.114";
const char* mqtt_server = "192.168.1.101";

/* UDP Settings */
WiFiUDP udp;
uint32_t udp_port = 3333;
const char* udp_server = "192.168.1.104";
double udp_buffer[PAYLOAD_SIZE];
uint32_t t_udp = 0;

WiFiClient espClient;
PubSubClient client(espClient);
long lastMsg = 0;
char msg[50];

////////////////////////////////////////////
//      ESP-NOW Configuration       ////////
////////////////////////////////////////////


uint8_t mac_leader[] = {0x1A, 0x2B, 0x3C, 0x4D, 0x5E, 0x6F};		// custom MAC
uint8_t mac_list[][6] = { {0x24, 0x0A, 0xC4, 0x31, 0x34, 0x18},   // lider
                          {0x24, 0x0A, 0xC4, 0x32, 0x0E, 0x20},   // 2do
                          {0x24, 0x0A, 0xC4, 0x32, 0x14, 0x80},   // 3ro
                          {0x24, 0x0A, 0xC4, 0x32, 0x37, 0xAC}    // 4to
                        };
uint8_t mac_addr_broadcast[] = {0xFF, 0xFF, 0xFF, 0xFF, 0xFF, 0xFF};
bool received, resend;      // control variables
uint32_t rcv_time = 0;

typedef struct {
	uint32_t timestamp;
	double position;
	double velocity;
} ESPNOW_payload;

//ESPNOW_payload monitor_data;
double monitor_data[5];
double data_com[2];
ESPNOW_payload rcv_data;

esp_now_peer_info_t peerInfo;   // struct to add peers to ESPNOW

////////////////////////////////////////////////////
//          DC Motor Configuration      ////////////
////////////////////////////////////////////////////
const int Control_fwd = 25;                //  Pin AIN1  [rotation direction + control]
const int Control_back = 26;            //  Pin AIN2   [rotation direction - control]
const int Control_v = 12;                 //  Pin PWMA    [rotation speed control]
int MotorSpeed = 0;                   // Motor speed from 0 to 1024
int MotorDirection = 1;               // Forward (1) or Backwards (0)
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

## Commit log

2021-01-10 readme esp32 code
2021-02-04 Create stl
2021-02-04 deleted extra files
    [1W_star_LED.stl, 9V Battery.stl, ADNS 3080.stl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]
2021-02-05 Se agrega Link de Video en README
2021-03-23 clean PID agents code
2021-03-27 uploaded code to calibrate the camera lens
2021-03-27 name change to *.ino files and small typos fixed
    [LeaderAgent.ino, PIDAgents.ino, esp_setup.ino]
2021-03-31 lens calibration readme
2021-09-29 added led to indicate when the setup is done
2021-11-30 Codigo Diego tracking velocidad
2021-12-02 codigo correccion de datos Cristóbal
2021-12-02 Código para control crucero con comunicación entre carro
2022-04-21 revision codigo control posicion con comunicacion
    [asd.csv, cosine.csv, lambda0.csv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]
2022-04-28 fix eje temporal matplot_realtime
    [matplot_realtime.py]
2022-05-04 mod plot
    [asd.csv, prueba_04-05_step.csv]
2022-05-27 pruebas delay 27-05
    [delay_1k.csv, delay_1k_eta_02.csv, delay_2k.csv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]
2024-10-04 Kicad PCB 1st version
    [PL_Toon.kicad_pcb, PL_Toon.kicad_sch]
2025-02-14 Update the PCB files
    - Updated the files, to take into account small changes like Do Not Populate, and add resistors values to 330 Ohm in the case of the LED resistors.
    - Added Bill Of Material
    [PL_Toon.kicad_pcb, PL_Toon.kicad_sch]
2025-02-14 Some Pictures of the PCBs
2025-02-14 Update README.md
    Working in progress, writing description of the PCB
2025-02-14 Simple test code for hardware
    - test motor
    -Test dist sensor
2026-06-19 Add laptop-free mobile dashboard (ESP32-S3 AP + WebSocket + LittleFS)
    Mobile mode of PL-TOON: the ESP32-S3 hosts its own WiFi access point and
    serves a web control dashboard (PID / step-response / deadband) to a phone
    over a WebSocket, served from LittleFS, with no laptop, MQTT broker, or app.
    Single-train laboratory; companion to the TICxEd 2026 paper.
    [partitions.csv]
2026-07-03 Add closed-loop experiment videos referenced in the mobile-dashboard paper
    - single_train_demo_2026-07-03.mp4: current fw 2.4.1 untethered demo
    - zn_gain_progression.mp4, pid_step.mp4: fw 2.3 illustrative clips
    - README documents per-clip firmware/tether provenance
2026-07-03 Sync mobile firmware to 2.4.1 + dashboard with Link Latency card; add live-dashboard video
    - tren_esp_mobile.ino 2.3 -> 2.4.1-mobile: non-blocking VL53L0X read (true 50 ms
    control loop), 6-tap sensor moving average, cross-core parameter handoff,
    LittleFS fail-loud mount, targeted acks, GET /heap endpoint
    - data/index.html: Link Latency card (in-browser RTT probes + CSV export),
    copy-based data export for captive-WebView cases, presets row
    - videos/dashboard_live_2026-07-03.mp4: screen capture of the dashboard served
    by the train plotting a live PID step in real time (fw 2.4.1, untethered)
    [tren_esp_mobile.ino]
2026-07-06 Firmware 2.4.2-mobile: optional step-mode brake phase (coast / short-brake / reverse-torque)
    Adds brk_mode / brk_pwm / brk_ms WebSocket commands; telemetry streams
    through the brake phase with live motor direction. Backward compatible
    (default = legacy stop). Built for direction-asymmetry diagnostics:
    matched-speed stopping tests that separate drivetrain, driver, and
    ToF-sensing effects.
    [tren_esp_mobile.ino]
2026-08-28 Add 3MF print files for the train chassis parts
    Adds Hardware/3D_Printed_Parts with the 3MF models for the PLTOON
    train pieces: front and rear chassis parts (single and 8-up print
    plates) and the washer.
    Claude-Session: https://claude.ai/code/session_01E8WxYyvYUewCYVJxsg5eet
    [Arandela_trencito.3mf, PIEZA_FRONTAL_TREN_DUPLICADAx8.3mf, PIEZA_FRONTAL_TREN_IMPRIMIR.3mf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]
2026-08-28 Document the 3d printed train parts in the Hardware README
    Adds a section pointing at Hardware/3D_Printed_Parts and a table
    describing each 3MF file, including the _IMPRIMIR (single copy) vs
    _DUPLICADAx8 (8-up plate) naming.
    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
2026-09-24 Firmware 2.5.0-mobile: seq field in data frames + dashboard event/link logging
    Firmware: per-boot monotonic seq in every "t":"d" frame (server-queue
    drop counting over TCP); data-frame buffer 256->320 B so the PID frame
    with seq cannot truncate silently.
    Dashboard: session event log (schema v1: mode switches, parameter
    changes old->new, start/stop incl. ESP-side auto-stop, exports,
    ws connect/disconnect), auto RTT sample every 30 s via the existing
    ref-ack probe, seq-gap counting with reconnect baseline reset,
    localStorage persistence with page-reload recovery, "Exportar
    registro" button, and # header lines (train id, fw, schema, wall
    clock) on both CSV exports.
    Patch report: Paper/75_pl_t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
    [tren_esp_mobile.ino]
2026-11-06 tren_esp_mobile 2.5.2: Ki and Kd up to 150, motor safety guard
    - Ki and Kd are accepted up to 150, the maximum of the dashboard sliders.
    The firmware clamped them to 50, so the slider silently snapped back.
    - Motor safety guard: any running experiment stops when the PWM is 250 or
    more and the distance moves less than 0.5 cm in 1.5 s (stall), when the
    train comes closer than 8 cm to the object in the step and deadband modes,
    or when the sensor delivers no fresh sample for 1 s. The guard only reads
    the PWM and the filtered distance; the PID law and its 50 ms timing are
    unchanged.
2026-11-06 tren_esp_mobile README: re-flashing trains from 2.5.0, OTA cautions
    Adds a section on the one-time USB update of trains still on 2.5.0 or
    earlier: board settings, nvs survives, LittleFS and firmware in the same
    session at the new offset, upload through the IDE so otadata is written,
    one train first. The OTA notes now state that any differing release
    version installs (including an older one), the boot delay with SET_WIFI
    stored, that RESET_TRAIN keeps the Wi-Fi credentials, and which networks
    work.
